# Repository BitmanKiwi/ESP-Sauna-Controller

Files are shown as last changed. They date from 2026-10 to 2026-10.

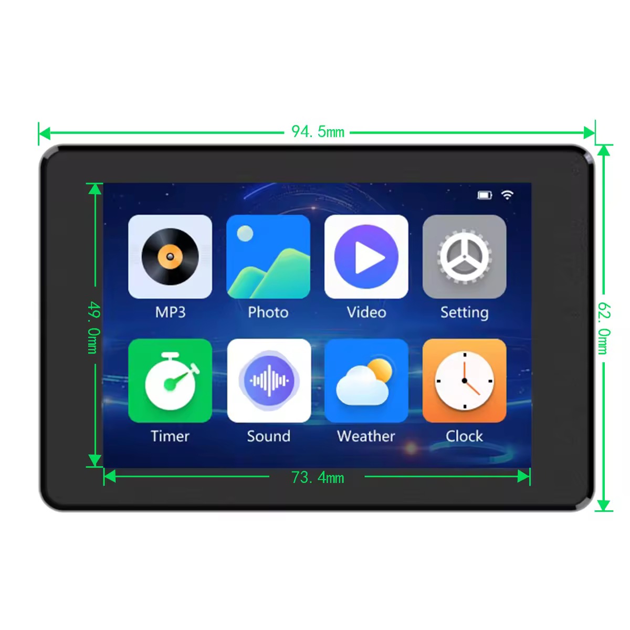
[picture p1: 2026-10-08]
docs/JC3248W535/structure/product-image-04.jpg

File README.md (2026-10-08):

# ESP Sauna Controller

ESPHome firmware for a DIY sauna controller on a **JC3248W535** touchscreen board (ESP32-S3).
It switches the heater through an SSR, runs a timed session, controls the lights, and serves its own web page.

Shamelessly built with Claude's assistance.

The touchscreen board is linked under [Parts](#parts) (AliExpress). I used KiCad to design a breakout PCB for it.
To reach the board's IO you will need two 4-pin and one 8-pin JST 1.25 pigtails.

> **Safety:** this controller switches a mains-powered heater. Mains wiring should be done by a licensed electrician.
> Don't rely on the firmware alone to prevent overheating. Fit an independent hardware over-temperature cutoff
> (a thermal fuse or limit thermostat) in the heater circuit, and test it.

## Features

- Thermostat with an adjustable setpoint and deadband (hysteresis)
- Thermocouple reading (K-type through a MAX31855) with spike rejection and averaging
- Run timer: a fresh run starts when the "enabled" input goes live, and heating stops when it runs out
- Reset and End buttons for the run, on the touchscreen and on the web page
- Lights output, with a separate temperature correction while the lights are on
- Switched supply for an internal thermometer
- Custom web page (mobile friendly): temperature, 60-minute chart, countdown, controls and settings
- Safety: an implausible or missing temperature reading switches the heater off

## Files

| File | Purpose |
|---|---|
| `sauna-controller.yaml` | The ESPHome configuration |
| `www/sauna-page.js` | The custom web page, built into the firmware |
| `secrets.example.yaml` | Template for `secrets.yaml` (copy and fill in) |
| `docs/JC3248W535/` | Board specification, pin map, slot drawings, chip datasheets, user manual |
| `PCB/` | KiCad project for the breakout/interface board |

## Pins (as wired)

| Function | GPIO | Notes |
|---|---|---|
| Heater SSR | 15 | Firmware-controlled only |
| Lights SSR | 16 | |
| Thermometer supply | 9 | |
| Enable input | 17 | On a board built from an earlier version of the PCB, silkscreened "IO18" (see Breakout PCB) |
| MAX31855 | 5 (DO), 6 (CS), 7 (CLK) | Separate SPI bus |

## Setup

1. Copy `secrets.example.yaml` to `secrets.yaml` and fill in your own values. `secrets.yaml` is git-ignored.
2. From the folder containing the yaml, build and flash:

   ```
   esphome run sauna-controller.yaml
   ```

3. Open the controller's address in a browser and sign in as `admin` with your `web_password`.

The web login is plain HTTP, so keep the controller off the internet.

## Using it

### Install and first flash

1. Install ESPHome (needs Python): `pip install esphome`. Check it with `esphome version`.
2. Create `secrets.yaml` (see above), then connect the board by USB and run `esphome run sauna-controller.yaml`. Pick the serial port when it asks.
3. After that first flash, `esphome run sauna-controller.yaml` can update it over WiFi (OTA). It asks for the `ota_password` from `secrets.yaml`.
4. The first build takes a few minutes. Later ones are faster because ESPHome keeps a build cache in `.esphome/`. That folder is generated, so it is git-ignored and safe to delete. The next build recreates it.

If a change doesn't seem to take effect, check the end of the `esphome run` output for a successful upload, and confirm the file you edited is the one you ran.

### How a run works

- The controller only heats while the **enable input** (GPIO17) is on, for example from a smart switch in series with the element power.
- When the input goes on, a fresh run starts (75 minutes by default, set by `run_time_minutes` at the top of the yaml) and the sauna heats to the setpoint.
- When the time runs out, heating stops and the status shows **Times Up**. **Reset** starts a fresh run if the input is still on. **End** stops the run immediately.
- If the input goes off, the run is cleared. The next time it goes on, you get a full new run.
- The status shows **Ready** (input on), **Not Ready** (input off) or **Times Up**.

### Web page

Open the controller's address in a browser and sign in as `admin`.

- The page shows the temperature, a heating indicator, a 60-minute chart (dashed line is the setpoint, shaded bands are heating), and the time left.
- **Reset** and **End** are side by side. Use the **−** and **+** buttons or type a number for the setpoint.
- The lights button turns the lights on and off.
- **Settings** holds the deadband (how far below the setpoint before the heater turns back on), the calibration offset, the offset with the lights on, the thermometer supply switch, and a two-decimal reading for calibration.
- The footer says when data last arrived. If it reports missing items, an entity name in the yaml has changed and the page needs updating to match.
- Add `?stock` to the address to load ESPHome's stock page instead. That needs internet on the device you're browsing from.

### Touchscreen

- Tap the lights circle (centre) to toggle the lights.
- Tap the time remaining to reset the run.
- Tap the heating LED (right of the timer) to end the run.
- **−** and **+** at the bottom change the setpoint.

### Calibration

1. Set **Calibration offset** so the reading matches a reference thermometer. Use a stable temperature and wait about 20 seconds for the filters to settle.
2. If the reading shifts when the lights come on, note the difference between lights off and lights on, and enter it (with the opposite sign) in **Offset with lights on**.
3. Check at a second, hotter temperature. If the shift changes, it isn't a fixed offset.

### Temperature filtering and safety

Readings pass through a plausibility check (below −20 °C or above 160 °C raw is discarded), a median filter, a moving average, and then the calibration offset. If no valid reading arrives for 30 seconds, the controller treats the temperature as unknown and keeps the heater off.

### Troubleshooting

- **Page is blank or shows the stock list:** the browser may be caching it. Hard-refresh (Ctrl+F5, or Cmd+Shift+R on a Mac) after a flash.
- **Noisy or jumping temperature:** keep the thermocouple cable apart from other wiring, ground its screen at the controller end only, and use a clean 12 V supply for the lights.
- **Heater won't turn on:** check the enable input, that the status isn't **Times Up**, and that the temperature is below the setpoint minus the deadband.

## Board IO connectors

From the vendor schematic ("Extended IO" sheet). Check the connector pitch and pin 1 against your own board before wiring.

| Connector | Pins (1 to last) | Used here |
|---|---|---|
| F2 (8-pin) | IO5, IO6, IO7, IO15, IO16, IO46, IO9, IO14 | IO5, IO6, IO7 (MAX31855), IO15 (heater), IO16 (lights), IO9 (thermometer supply) |
| P3 (4-pin) | GND, 3.3V, IO17, IO18 | IO17 (enable input) |
| P4 (4-pin) | GND, 3.3V, IO17, IO18 | Same signals as P3 (the schematic labels this one as a different pitch from P3) |

## Breakout PCB

The `PCB/` folder holds the KiCad project (`Sauna Controller Interface.kicad_pro` and `.kicad_pcb`) for the interface (breakout) board that breaks out the controller's IO.

If you want to have the board made, open the KiCad files and generate your own output files (Gerbers and drill files) from them, using your manufacturer's settings. No Gerber files are included, so the output always matches the design you open. Check the design against your own wiring before ordering. 

**Silkscreen fix:** the first version of this board had the IO17 and IO18 silkscreen labels on the two output headers the wrong way round. That is corrected in the KiCad files here. The enable input is GPIO17, and on a board built from the earlier version it is printed "IO18". Wire by function and the connector table above, not by the silkscreen, if you have one of those boards.

## Parts

- [Product page (AliExpress)](https://www.aliexpress.com/item/1005007566332450.html)

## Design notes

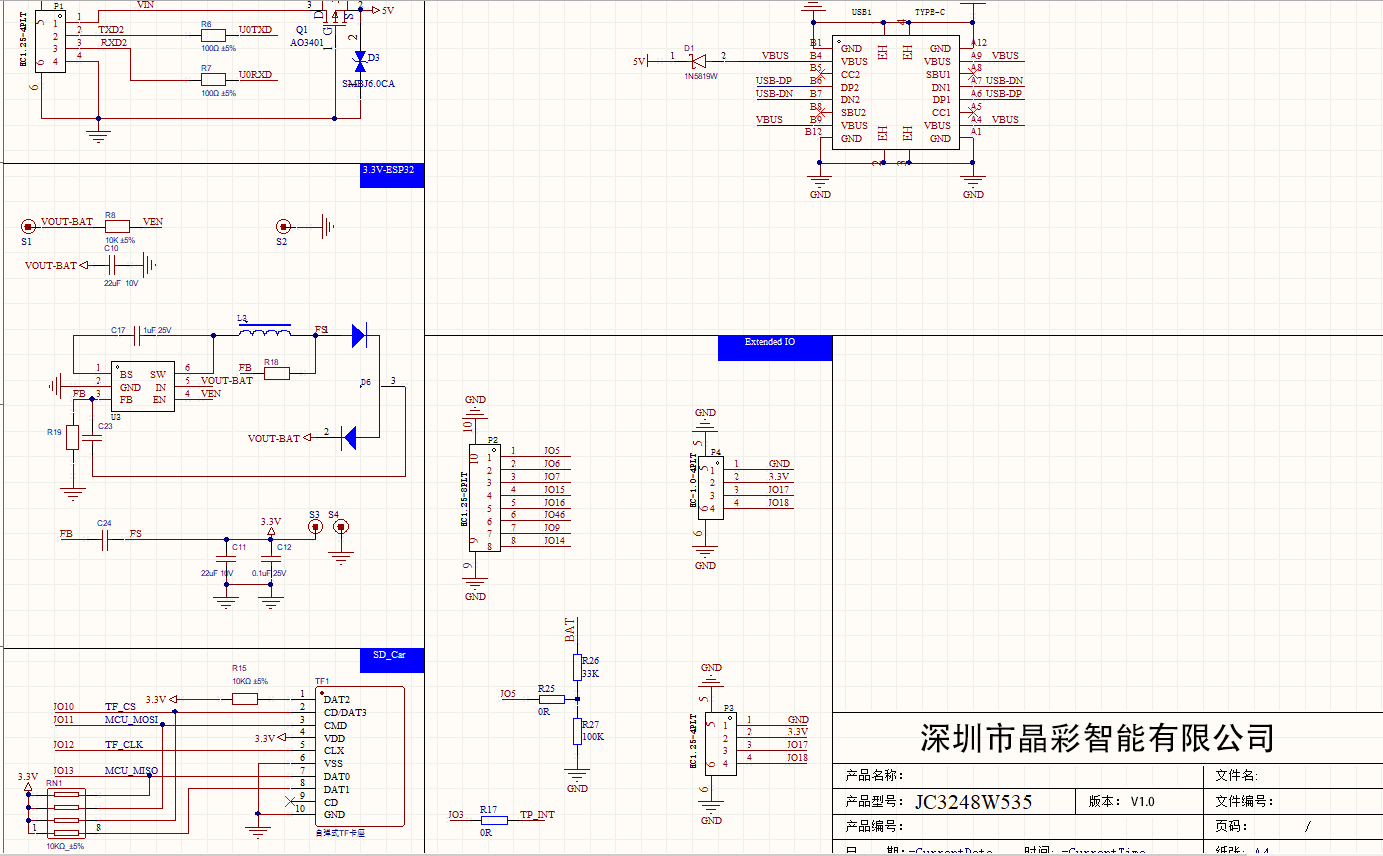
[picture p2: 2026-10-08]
docs/JC3248W535/io-pins/JC3248W535-1.png

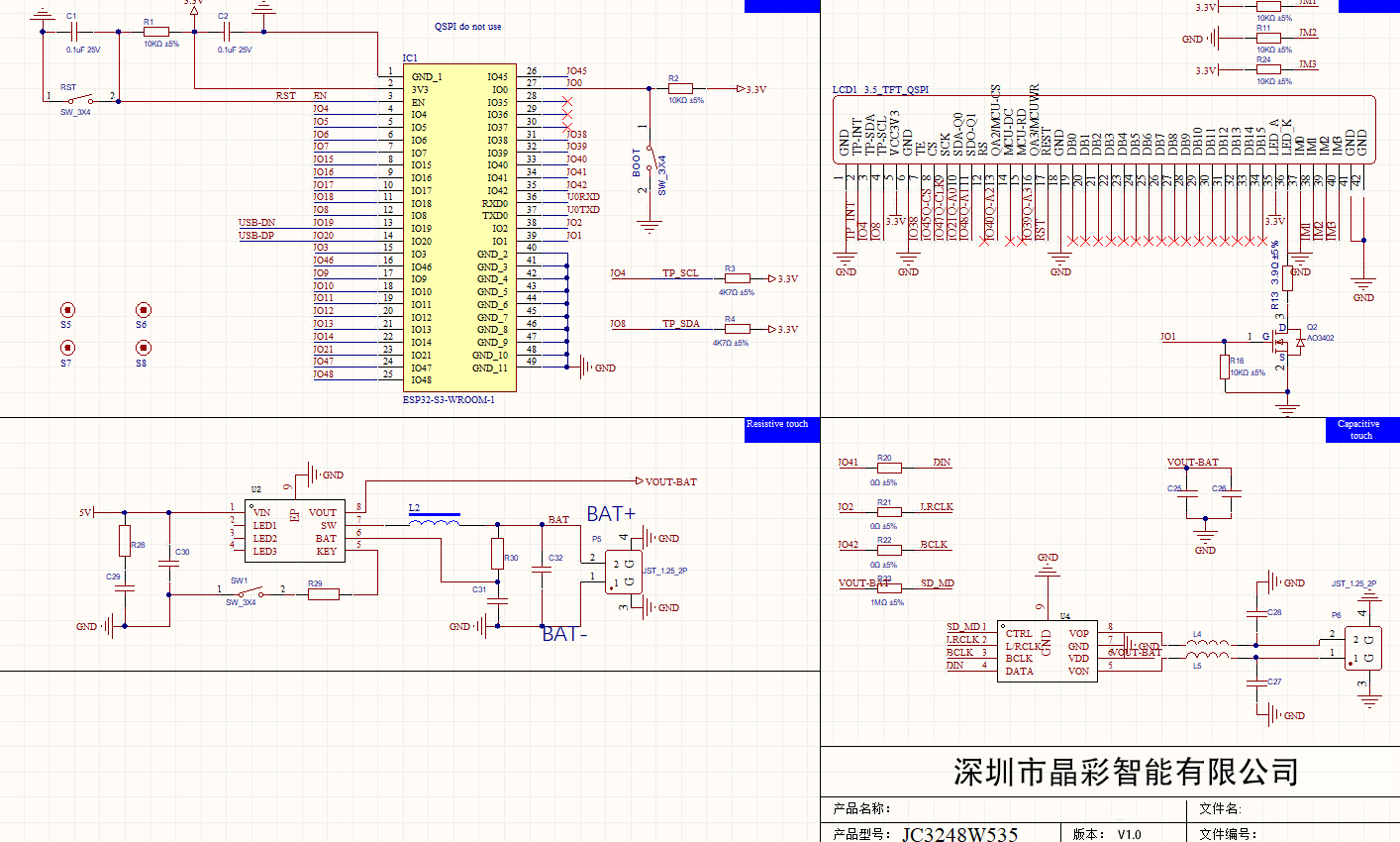
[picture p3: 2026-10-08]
docs/JC3248W535/io-pins/JC3248W535-2.png

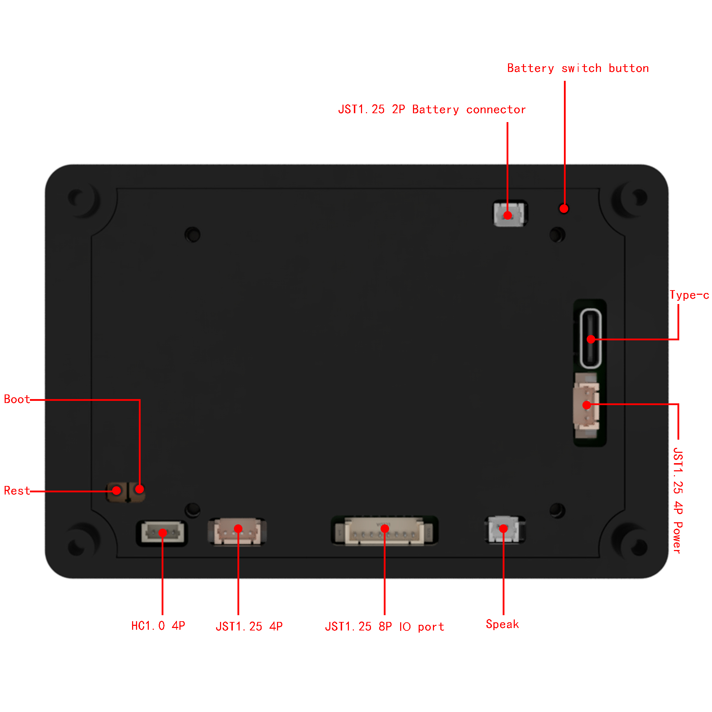
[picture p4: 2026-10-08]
docs/JC3248W535/structure/product-image-07.jpg

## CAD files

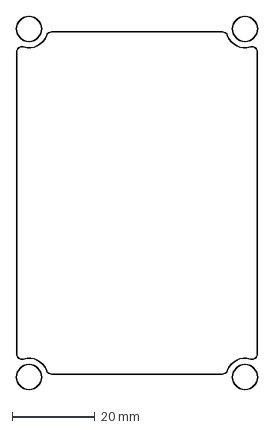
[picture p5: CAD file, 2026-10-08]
docs/JC3248W535/structure/Slot method 1.dxf
58.4 x 90.4 mm

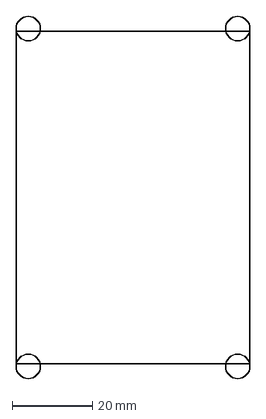
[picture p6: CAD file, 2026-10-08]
docs/JC3248W535/structure/Slot method 2.dxf
58.4 x 90.4 mm

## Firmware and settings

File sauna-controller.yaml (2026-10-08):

substitutions:
  run_time_minutes: "75"   # hard-coded session length — change here, not via the UI

esphome:
  name: sauna-controller
  friendly_name: Sauna Controller Production

esp32:
  board: esp32-s3-devkitc-1
  variant: esp32s3
  flash_size: 16MB
  framework:
    type: esp-idf

psram:
  mode: octal
  speed: 80MHz

wifi:
  ssid: !secret wifi_ssid
  password: !secret wifi_password

logger:
  level: NONE   # serial logging off (USB serial activity was adding noise to the thermocouple readings)

api:
  encryption:
    key: !secret api_encryption_key

ota:
  platform: esphome
  password: !secret ota_password

# Browser dashboard — custom page (www/sauna-page.js) replaces the stock entity list.
# js_url: "" stops ESPHome loading its stock UI from the internet; the page is fully
# self-contained and works offline. Do NOT add `local: true` — that ignores js_include.
# Add ?stock to the address to try the stock UI instead (needs internet on the phone).
web_server:
  version: 3
  js_url: ""
  js_include: "www/sauna-page.js"
  auth:
    username: admin
    password: !secret web_password

# Run-time session tracking: a fresh session starts automatically the moment
# Heater Enabled (GPIO17) goes true. When it elapses, heating is blocked until
# a manual reset (web button or touchscreen tap).
globals:
  - id: session_active
    type: bool
    restore_value: false
    initial_value: 'false'
  - id: session_expired
    type: bool
    restore_value: false
    initial_value: 'false'
  - id: session_start_ms
    type: uint32_t
    restore_value: false
    initial_value: '0'

# Onboard touch controller — dedicated I2C pins (GPIO4/GPIO8) with onboard pull-ups, no external wiring
i2c:
  sda: GPIO4
  scl: GPIO8
  frequency: 400kHz

touchscreen:
  platform: axs15231
  id: sauna_touch
  interrupt_pin: GPIO3
  # Raw touch coords already match the display's native orientation
  # (x ~11-309 left-to-right, y ~67-460 top-to-bottom), so no swap/mirror is needed.
  # If buttons ever stop responding, re-run a 4-corner raw-coordinate test before changing this.
  transform:
    swap_xy: false
    mirror_x: false
    mirror_y: false
  on_touch:
    then:
      - lambda: |-
          int x = touch.x;
          int y = touch.y;
          // Minus button: bottom-left
          if (x > 20 && x < 120 && y > 380 && y < 440) {
            id(set_temp).make_call().set_value(id(set_temp).state - 1).perform();
          }
          // Plus button: bottom-right
          if (x > 200 && x < 300 && y > 380 && y < 440) {
            id(set_temp).make_call().set_value(id(set_temp).state + 1).perform();
          }
          // Light toggle — circle centred at (160,200), radius 30
          if (x > 130 && x < 190 && y > 170 && y < 230) {
            id(lights).toggle().perform();
          }
          // Time remaining — tap to reset the run timer (zone kept clear of the Heat LED)
          if (x > 80 && x < 200 && y > 280 && y < 320) {
            id(reset_timer).execute();
          }
          // Heat LED — tap to end the run early (circle centred at (250,300))
          if (x > 230 && x < 270 && y > 280 && y < 320) {
            id(end_timer).execute();
          }

text_sensor:
  - platform: template
    id: sauna_status
    name: "Sauna Status"

  - platform: template
    id: enabled_status
    name: "Heater Enabled"

button:
  - platform: template
    name: "Reset Run Timer"
    id: reset_run_timer
    on_press:
      then:
        - script.execute: reset_timer

  - platform: template
    name: "End Run Timer"
    id: end_run_timer
    on_press:
      then:
        - script.execute: end_timer

binary_sensor:
  # GPIO17 — enable input from the relay monitoring the external smart switch in
  # series with the element power. Relay contact is assumed to pull the pin to GND
  # when enabled, so it's inverted: true = enabled. Flip `inverted` if that's backwards.
  # NOTE: this is the pad silkscreened "IO18" on the interface PCB (IO17/IO18 labels are swapped).
  - platform: gpio
    pin:
      number: GPIO17
      mode: INPUT_PULLUP
      inverted: true
    id: heater_enabled
    name: "Heater Enabled"
    internal: true   # raw reading only — the "Heater Enabled" text_sensor (Ready/Not Ready/Times Up) is what's shown
    on_state:
      then:
        - script.execute: update_heater

  # Read-only mirror of the heater output's state — shows as an LED-style indicator on the
  # web UI, since the heater switch itself is internal (firmware-controlled only)
  - platform: template
    id: heater_status
    name: "Sauna Heater"
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

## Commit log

2026-10-08 Sauna controller: ESPHome config, custom web page, board docs
    [Slot method 1.dxf, Slot method 2.dxf, sauna-controller.yaml]
2026-10-08 Fix IO17/IO18 silkscreen labels, add PCB project, update README
    [Sauna Controller Interface.kicad_pcb]
